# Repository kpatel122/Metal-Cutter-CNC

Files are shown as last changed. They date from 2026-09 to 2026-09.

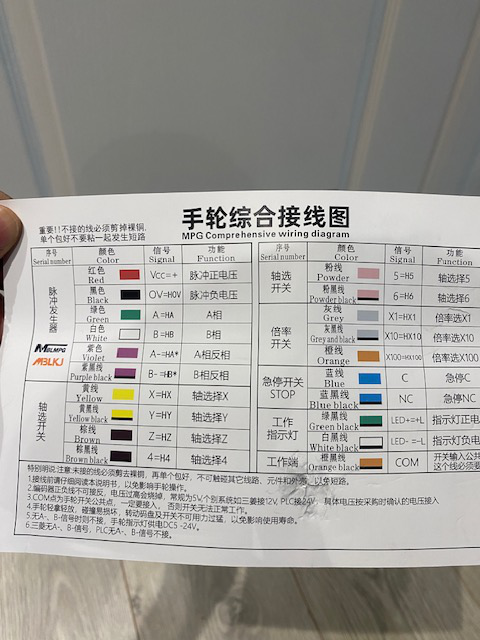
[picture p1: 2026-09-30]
MPEG Handwheel/encoder1.JPG

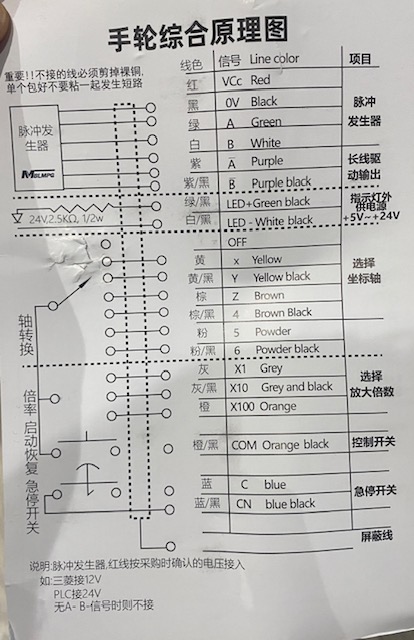
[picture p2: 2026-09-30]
MPEG Handwheel/encoder2.jpg

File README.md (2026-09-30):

# Metal Cutter CNC Machine
PrintNC Implementation based on the Metal Cutter variation.
https://wiki.printnc.info/en/home

(https://youtu.be/oM1bcv8IxZg)

Shield: [][cc-by-nc-sa]

This work is licensed under a
[Creative Commons Attribution-NonCommercial-ShareAlike 4.0 International License][cc-by-nc-sa].

[][cc-by-nc-sa]

[cc-by-nc-sa]: http://creativecommons.org/licenses/by-nc-sa/4.0/
[cc-by-nc-sa-image]: https://licensebuttons.net/l/by-nc-sa/4.0/88x31.png
[cc-by-nc-sa-shield]: https://img.shields.io/badge/License-CC%20BY--NC--SA%204.0-lightgrey.svg

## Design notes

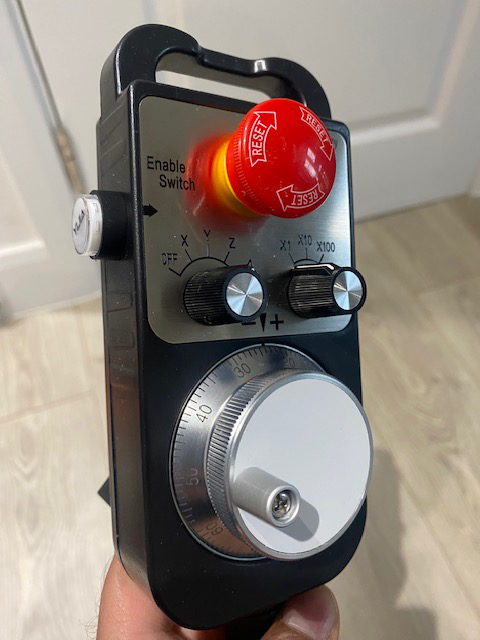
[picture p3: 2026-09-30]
MPEG Handwheel/encoder_pic.JPG

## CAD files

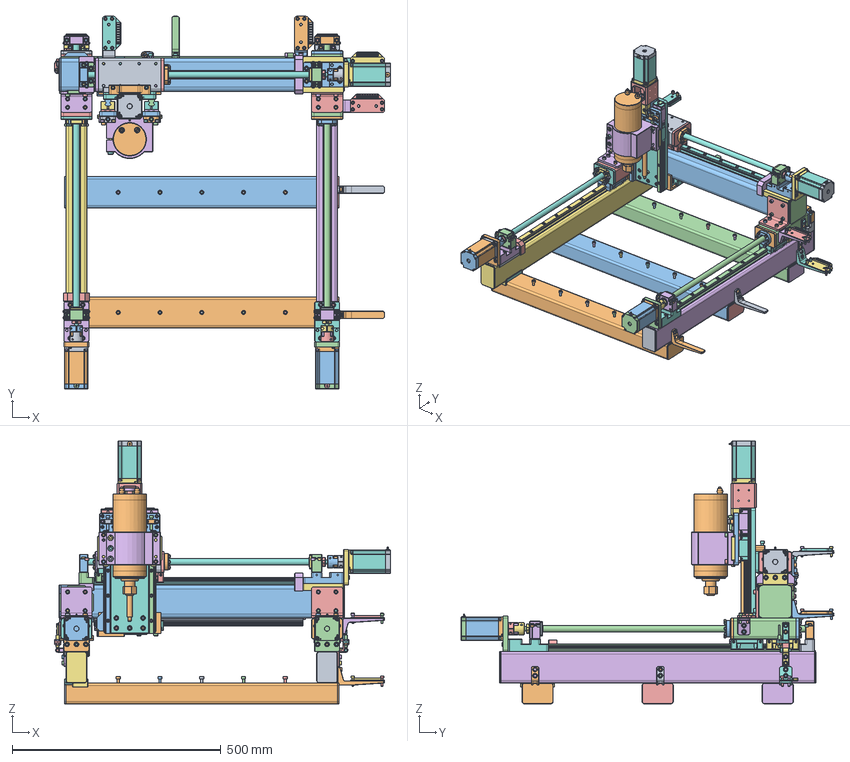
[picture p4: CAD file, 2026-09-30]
CAD/metal-cutter.FCStd
804.3 x 891.8 x 629.0 mm
Wasteboard M6x20
Wasteboard M6x001
Wasteboard M6x002
Wasteboard M6x003
Wasteboard M6x004
Wasteboard M6x005
Wasteboard M6x006
Wasteboard M6x007
Wasteboard M6x008
Wasteboard M6x009
Wasteboard M6x010
Wasteboard M6x011
Wasteboard M6x012
Wasteboard M6x013
Wasteboard M6x014
M6x12
M6x001
M6x002
M6x003
M6x004
M6x005
M6x006
M6x007
M6x008
M6x009
M6x010
M6x011
M6x012
M6x013
M6x014
M5x20
M5x001
M5x002
M5x003
M5x004
M5x005
M5x006
M5x007
M5x008
M5x009
M6x30
M6x016
M6x017
M6x018
M6x019
M6x020
M6x021
M6x50
M6x023
M6x024
M6x025
M6x026
M6x027
M4x16
M4x001
M4x002
M4x003
M6x50 (4)
M6x50 (4)001
M6x50 (4)002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

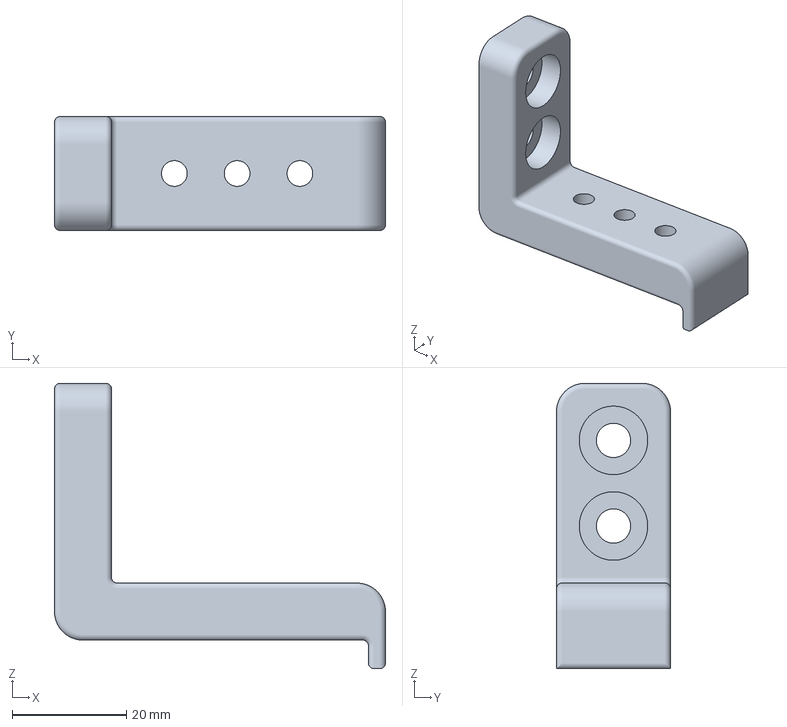
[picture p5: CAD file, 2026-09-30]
Fabrication/3D Printed Milled Parts/Common/chain-mount-holder-2-variation.3mf
58.0 x 20.0 x 50.0 mm

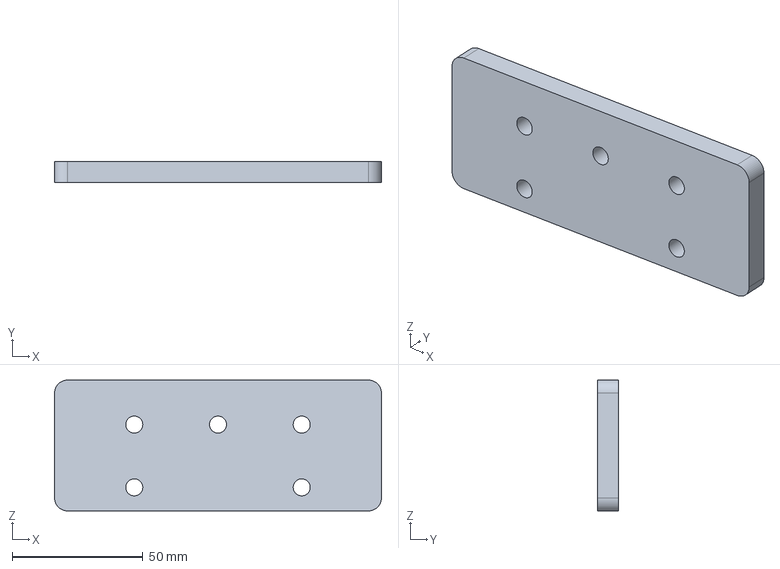
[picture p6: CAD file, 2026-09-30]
Fabrication/3D Printed Milled Parts/X Axis/XAxis-Shim.FCStd
125.0 x 8.00 x 50.0 mm

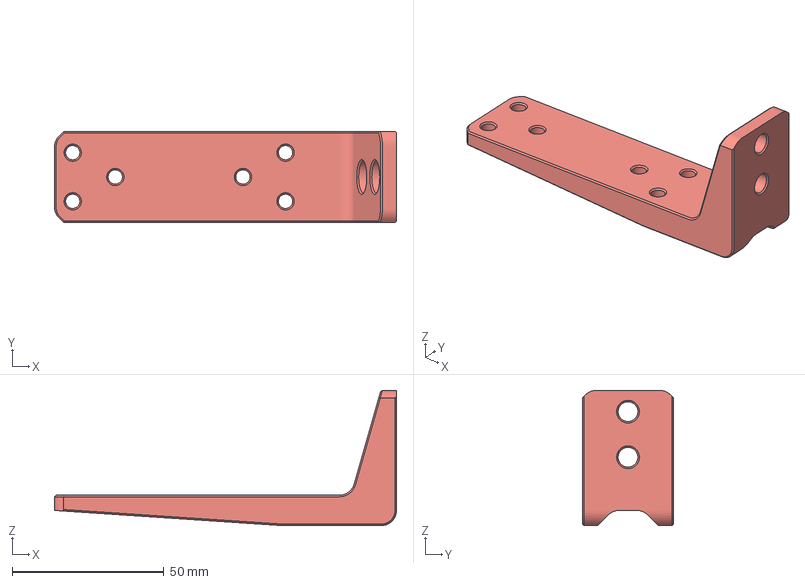
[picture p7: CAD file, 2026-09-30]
Fabrication/3D Printed Milled Parts/Y Axis/Cable-Chain/YChain-Fixed.3mf
112.5 x 30.0 x 44.5 mm

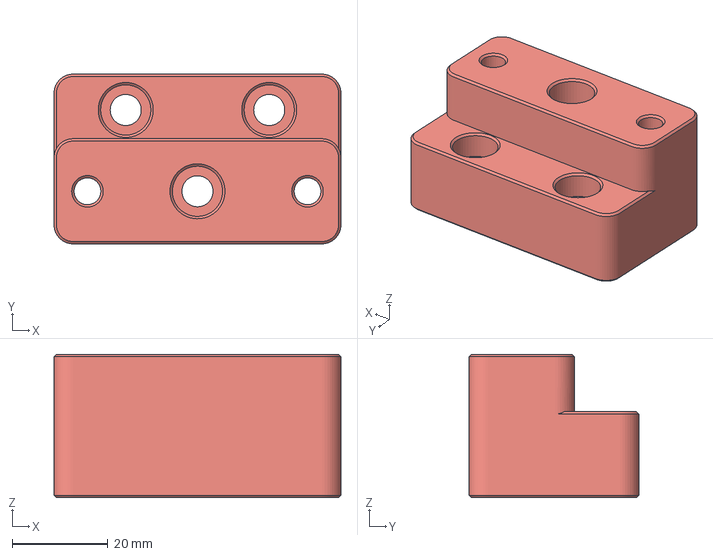
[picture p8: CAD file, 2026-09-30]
Fabrication/3D Printed Milled Parts/Y Axis/Y BF12 Riser.3mf
60.0 x 35.5 x 30.0 mm

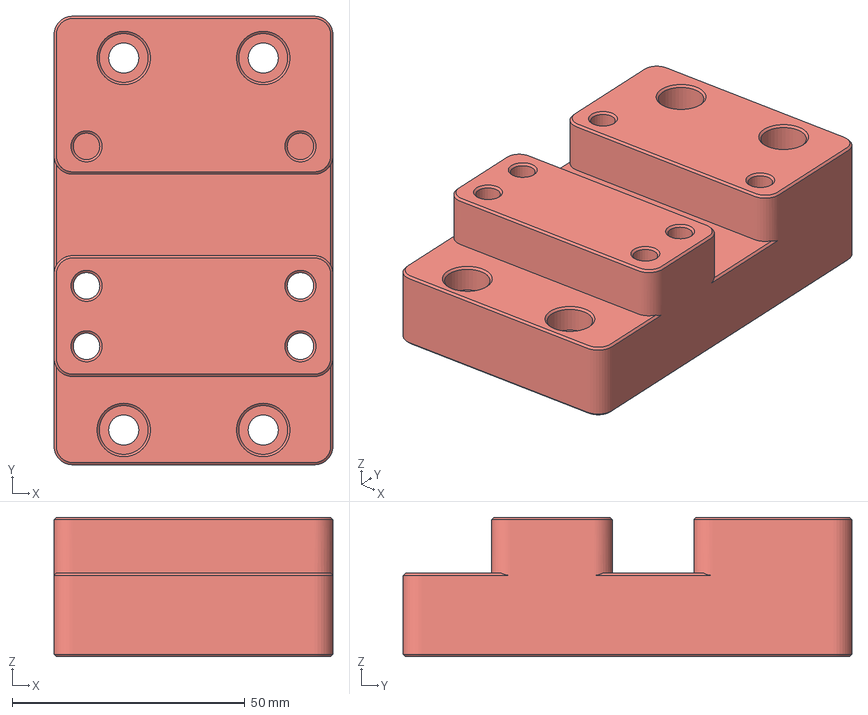
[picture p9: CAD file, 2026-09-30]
Fabrication/3D Printed Milled Parts/Y BKHM12 Riser.3mf
60.0 x 96.5 x 30.0 mm

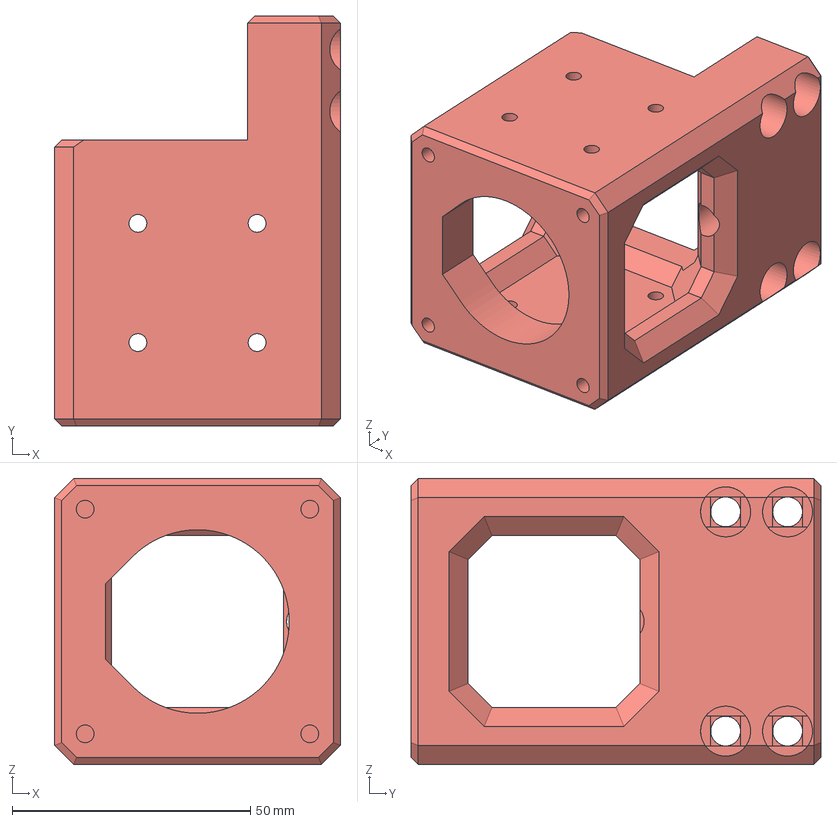
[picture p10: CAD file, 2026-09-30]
Fabrication/3D Printed Milled Parts/Z Axis/Z Nema23 Stepper Mount.3mf
60.0 x 86.0 x 60.0 mm

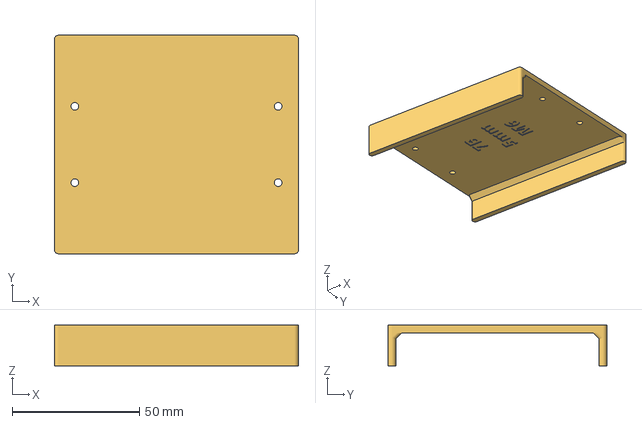
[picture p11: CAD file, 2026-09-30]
Fabrication/Printed Drill Guides/7B XGantry-BKHM Drill Guide.3mf
96.0 x 86.0 x 16.0 mm

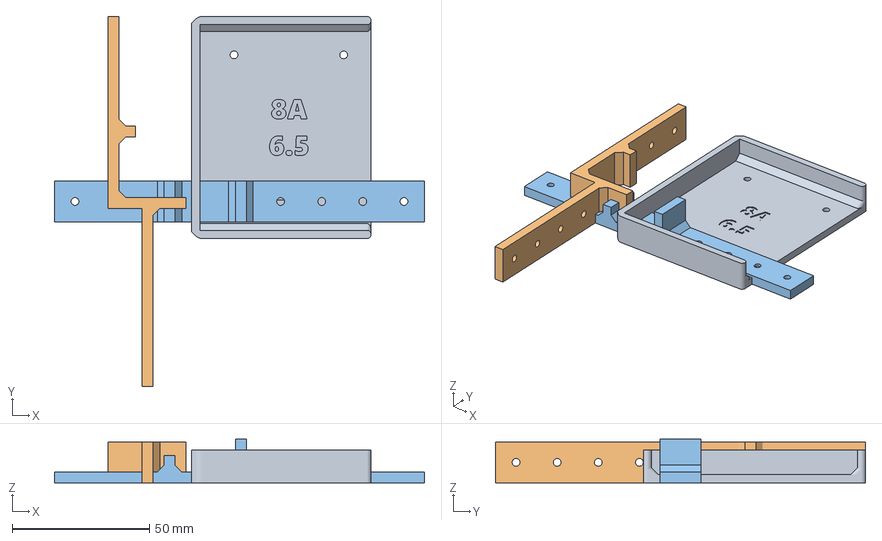
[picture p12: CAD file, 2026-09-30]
Fabrication/Printed Drill Guides/X Axis/8A X Top Roller-Carriage Drill Guide.3mf
135.0 x 135.0 x 16.0 mm
10A Yaxis Chain and Sensor Drill Guide
10B Xaxis Chain and Sensor Drill Guide

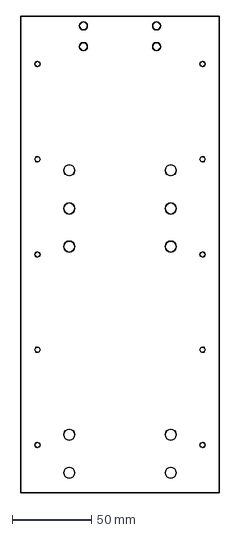
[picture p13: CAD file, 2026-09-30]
Fabrication/Z Axis/Wood Temp ZAxis/ZPlateTop.dxf
125.0 x 300.0 mm

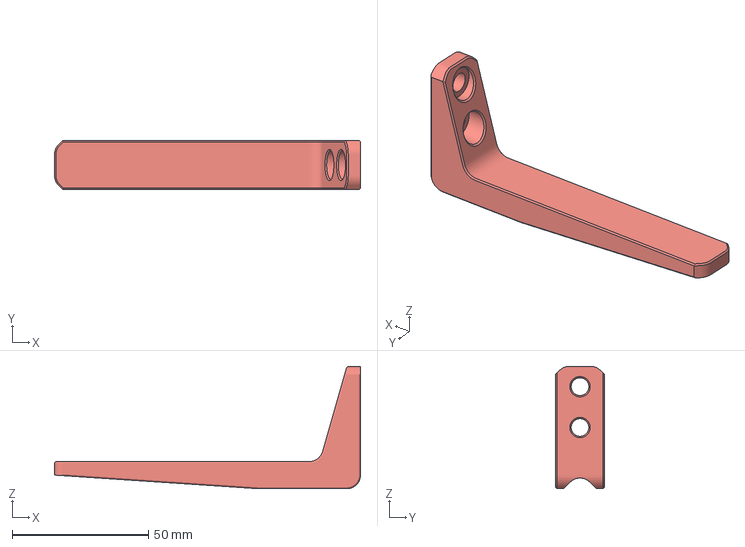
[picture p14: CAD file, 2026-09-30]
Fabrication/3D Printed Milled Parts/Y Axis/Cable-Chain/YChain-std.3mf
112.5 x 18.0 x 45.0 mm

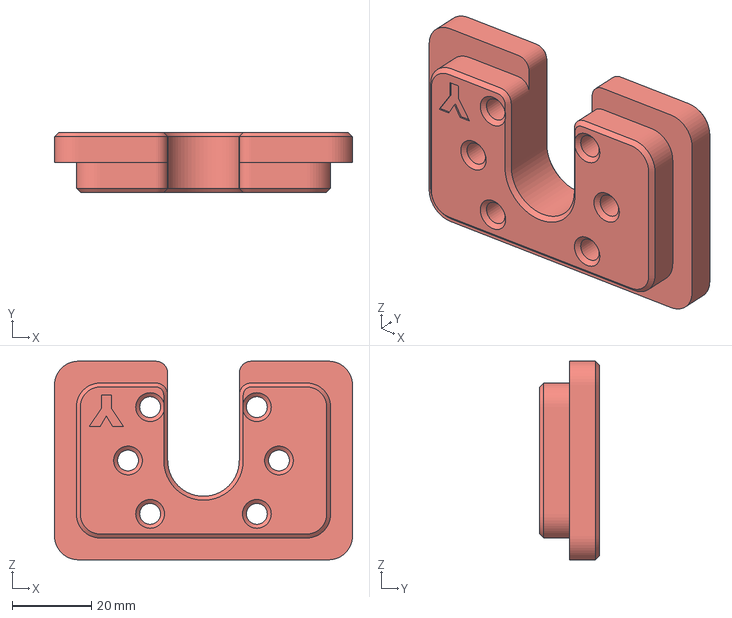
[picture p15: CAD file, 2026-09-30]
Fabrication/3D Printed Milled Parts/Y Axis/Y2 1610 Fill Plate.3mf
75.0 x 15.0 x 50.0 mm

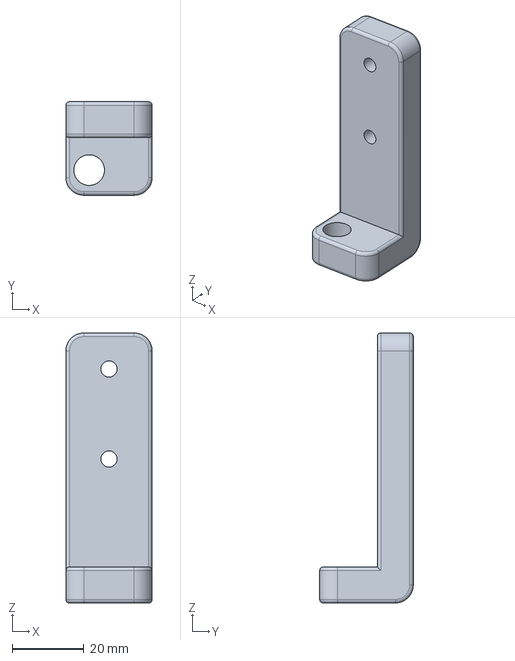
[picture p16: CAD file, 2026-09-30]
Fabrication/3D Printed Milled Parts/Z Axis/limit-switch-holder-z-axis.FCStd
24.0 x 26.0 x 75.0 mm

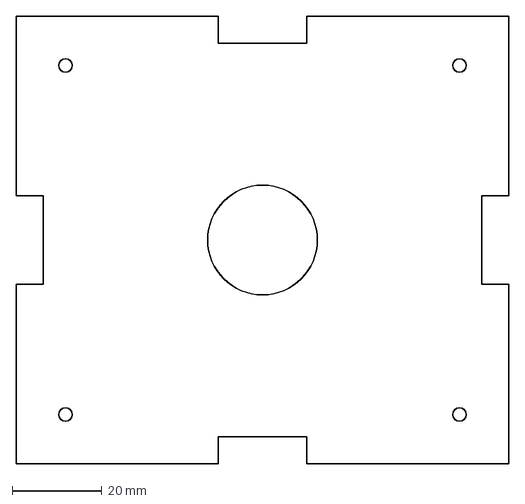
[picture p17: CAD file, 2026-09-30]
Fabrication/Front Panel/switch-panel-Sidesright.dxf
110.0 x 100.0 mm

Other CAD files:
Fabrication/Front Panel/switch-panel-front.dxf
Fabrication/3D Printed Milled Parts/Common/chain-mount-holder-2.3mf
Fabrication/3D Printed Milled Parts/X Axis/X BKHM12 Riser.3mf
Fabrication/3D Printed Milled Parts/Common/chain-mount-Body.3mf
Fabrication/3D Printed Milled Parts/Common/chain-mount-holder-1-variation.3mf
Fabrication/3D Printed Milled Parts/Common/chain-mount.FCStd
Fabrication/3D Printed Milled Parts/X Axis/7A XGantry-BF Drill Guide.3mf
Fabrication/3D Printed Milled Parts/X Axis/X 1610 Nut Plate.3mf
Fabrication/3D Printed Milled Parts/X Axis/X BF12 Riser.3mf
Fabrication/3D Printed Milled Parts/X Axis/X Nema23 Plate.3mf
Fabrication/3D Printed Milled Parts/X Axis/X-axis-homing-switch-mount.FCStd
Fabrication/3D Printed Milled Parts/X Axis/XAxis-Shim-Body.3mf
Fabrication/3D Printed Milled Parts/X Axis/XAxisOffesetBracket-Body.3mf
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

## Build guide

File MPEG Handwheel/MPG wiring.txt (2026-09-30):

P1 Expansion port
DB25	Mesa	MPG-wire-colour	Function
15		IO37	Brown			Z Select	
16		IO39	Yellow/Black	Y Select
17		IO41	Yellow			X Select
10		IO47	Gray			X1
11		IO48	Gray/Black		X10
12		IO49	Orange			x100
18		GND		Orangle/Black	switches GND (v5 gnd)

TB2
Mesa	MPG-wire-colour	Function 
1		White/Black		LED-
6		Green/Black		LED+
12		Red				+5V
9		Black			gnd (5v gnd)
7		Green			A+
8		Purple			A-
10		White			B+
11		Purple/Black	B-

TB3
Mesa	MPG-wire-colour	Function 
IO10 	Blue/Black		E-STOP-INPUT
GND     Blue			E-STOP-GND (24v gnd) (ground of 24V Power not 5v Power)

ESTOP WIRING (NC to GND)

MPEG and front panel estop wiring
IO10(mesa) -> Blue black wire mpeg (NC)->MPEG WHEEL ESTOP-> BLUE wire mpeg (COM)-> ETH breakout pin 6 -> PANEL ESTOP NC -> GND (ETH breakout GND)
Mesa IO10 → blue/black → [MPG NC] → blue → ETH pin 6 → [Panel NC] → GND

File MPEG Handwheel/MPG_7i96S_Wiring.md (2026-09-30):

# Wiring Guide: Mesa 7i96S to 18-Wire MPG Pendant

**Project:** PrintNC CNC Build  
**Date:** March 1, 2026  
**Hardware:** Mesa 7i96S Ethernet Card + 18-Wire Chinese MPG Pendant

---

### **Mesa Jumper Configuration**
To support the differential signals (A/A- and B/B-) from the pendant:
*   Set Jumpers **W1, W2, and W3** to the **RIGHT-HAND** position (Differential Mode).

---

## 2. Isolated Inputs: Axis & Multiplier (TB3)
The switches and buttons are wired to the isolated input block. This guide assumes a standard **24V Sourcing (PNP)** setup.

### **Input Mapping**
# Mesa MPG Wiring Reference

### P1 Expansion Port
| DB25 | Mesa | MPG-wire-colour | Function |
| :--- | :--- | :--- | :--- |
| 15 | IO37 | Brown | Z Select |
| 16 | IO39 | Yellow/Black | Y Select |
| 17 | IO41 | Yellow | X Select |
| 10 | IO47 | Gray | X1 |
| 11 | IO48 | Gray/Black | X10 |
| 12 | IO49 | Orange | x100 |
| 18 | GND | Orangle/Black | switches GND (v5 gnd) |

### TB2
| Mesa | MPG-wire-colour | Function |
| :--- | :--- | :--- |
| 1 | White/Black | LED- |
| 6 | Green/Black | LED+ |
| 12 | Red | +5V |
| 9 | Black | gnd (5v gnd) |
| 7 | Green | A+ |
| 8 | Purple | A- |
| 10 | White | B+ |
| 11 | Purple/Black | B- |

### TB3
| Mesa | MPG-wire-colour | Function |
| :--- | :--- | :--- |
| IO10 | Blue/Black | E-STOP-INPUT |
| 24v-GND | Blue | E-STOP-GND |

---

## 4. Auxiliary: LED & Enable Switch
*   **Indicator LED:** 
    *   **Green/Black (LED+):** Connect to +5V or +24V.
    *   **White/Black (LED-):** Connect to Ground.
*   **Enable/Deadman Switch:** This is the button on the side of the pendant. 
    *   **Identification:** Use a multimeter to check for continuity between **Orange/Black (COM)** and the **Brown/Black** wire while the side button is pressed.
    *   **Mesa Pin:** Connect the identified wire to **TB3 Pin 8 (Input 7)**.

---

## 5. Chinese Label Translation Table
| Chinese Label | English Translation |
| :--- | :--- |
| **轴选** (Zhóu xuǎn) | Axis Selection |
| **倍率** (Bèilǜ) | Multiplier (X1, X10, X100) |
| **急停** (Jí tíng) | Emergency Stop |
| **指示灯** (Zhǐshì dēng) | Indicator LED |
| **脉冲发生器** (Màichōng fāshēng qì) | Pulse Generator (MPG Wheel) |
| **COM** | Switch Common (Return Path) |

---

### **Pre-Power Validation**
Before turning on the machine:
1.  Check that the Red/Black power wires are not swapped.
2.  Verify that turning the Axis knob sends +24V to the expected Mesa Input pin.
3.  Ensure the E-Stop shows as "Closed" (high signal) when not pressed and "Open" (low signal) when pressed.

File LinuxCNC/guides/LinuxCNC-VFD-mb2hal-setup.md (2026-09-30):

# Optidrive E3 — mb2hal Setup (LinuxCNC Host)

Goal: replace the manual `mbpoll` commands in `commands.txt` with a HAL component
(`mb2hal`) that runs continuously inside LinuxCNC, exposing VFD run/stop, speed,
and status as HAL pins. These pins then get netted to the existing spindle
signals in `printnc-test1.hal` (`spindle.0.on`, `spindle.0.speed-out-abs`, etc.)
so the Axis GUI's existing spindle controls drive the VFD over Modbus.

Do all of this on the LinuxCNC controller machine, not the dev machine.

Syntax below is pulled directly from the LinuxCNC 2.9 docs
(`linuxcnc.org/docs/2.9/html/drivers/mb2hal.html`), matching your 2.9.8 install.

---

## 0. Before you start

- Confirm the RS485 connection works exactly as tested with `mbpoll` in
  `modbus-testing-guide.md` (same port, same 115200/8N1, slave ID 1).
- Have that file open — the register map (1 = control word, 2 = speed, 6 =
  status) and RPM-to-register scaling (register = RPM ÷ 6) come from there.
- **DI1 (hardware enable) is wired separately to Mesa OUT5 and is NOT part of
  this Modbus setup.** Don't remove or bypass that wiring — it's the fail-safe
  e-stop path and must keep working independently of whatever mb2hal is doing.

---

## 1. mb2hal.ini syntax reference

Two section types:

- `[MB2HAL_INIT]` — one global block
- `[TRANSACTION_00]`, `[TRANSACTION_01]`, ... — one per Modbus register you
  want to read or write

**`[MB2HAL_INIT]` keys:**

| Key | Required | Notes |
|---|---|---|
| `TOTAL_TRANSACTIONS` | Yes | Count of `[TRANSACTION_NN]` blocks below |
| `SLOWDOWN` | No | Seconds delay between transactions in the scan loop; `0.0` = as fast as possible |
| `HAL_MODULE_NAME` | No | Defaults to `mb2hal` — this is the prefix in all pin names |
| `INIT_DEBUG` | No | 0–4, startup log verbosity |

**`[TRANSACTION_NN]` keys:**

| Key | Required | Notes |
|---|---|---|
| `LINK_TYPE` | Yes | `serial` for our RS485 link |
| `SERIAL_PORT` | Only on first serial transaction | e.g. `/dev/ttyUSB0` |
| `SERIAL_BAUD` | Only on first serial transaction | `115200` |
| `SERIAL_BITS` | Yes | `8` |
| `SERIAL_PARITY` | Yes | `none` |
| `SERIAL_STOP` | Yes | `1` |
| `MB_SLAVE_ID` | Yes | `1` |
| `FIRST_ELEMENT` | Yes | Starting register **address** — see addressing warning below |
| `NELEMENTS` | Yes (unless using `PIN_NAMES`) | `1` for a single register |
| `MB_TX_CODE` | Yes | function code string, see table below |
| `HAL_TX_NAME` | No | custom name used in the resulting pin, max 28 chars |
| `MAX_UPDATE_RATE` | No | Hz cap on how often this transaction runs; `0.0` = unlimited |

**Function codes we need:**

| Purpose | `MB_TX_CODE` |
|---|---|
| Write control word / speed (FC6) | `fnct_06_write_single_register` |
| Read status word (FC3) | `fnct_03_read_holding_registers` |

**Resulting HAL pin names:** `mb2hal.<HAL_TX_NAME or transaction number>.<element index>.<type>`,
type being `.int` or `.float` for register transactions. With `NELEMENTS = 1`
the element index is always `00`.

** Addressing offset — confirmed correct on this install:**
The manual warns some Modbus masters use zero-based addressing and register
numbers may need `-1`. Confirmed empirically: with `FIRST_ELEMENT = 5`,
`vfd_status.00.int` read `64` (`0x0040`) when DI1 was enabled and `0` when
disabled — exactly the "No fault, Drive Ready" value documented in
`modbus-testing-guide.md` for register 6, and exactly matching the manual's
"bit 6 Drive Ready requires DI1 present" behavior. So `FIRST_ELEMENT =
register_number - 1` is correct:

| Manual register # | `mbpoll -r` | `FIRST_ELEMENT` |
|---|---|---|
| 1 (control word) | 1 | 0 |
| 2 (speed) | 2 | 1 |
| 6 (status) | 6 | 5 — confirmed live |

libmodbus applies this same zero-based convention uniformly across function
codes, so the two write transactions (registers 1 and 2) inherit the same
confirmed offset.

---

## 2. Draft `mb2hal.ini`

Create this next to `printnc-test1.hal`, e.g.
`/home/kp/Documents/Do_Backup/Projects/chips-cnc/LinuxCNC/mb2hal.ini`:

```ini
[MB2HAL_INIT]
TOTAL_TRANSACTIONS = 3
SLOWDOWN = 0.0
HAL_MODULE_NAME = mb2hal

[TRANSACTION_00]
LINK_TYPE = serial
SERIAL_PORT = /dev/ttyUSB0
SERIAL_BAUD = 115200
SERIAL_BITS = 8
SERIAL_PARITY = none
SERIAL_STOP = 1
MB_SLAVE_ID = 1
FIRST_ELEMENT = 0
NELEMENTS = 1
MB_TX_CODE = fnct_06_write_single_register
HAL_TX_NAME = vfd_control_word
MAX_UPDATE_RATE = 5.0

[TRANSACTION_01]
LINK_TYPE = serial
MB_SLAVE_ID = 1
FIRST_ELEMENT = 1
NELEMENTS = 1
MB_TX_CODE = fnct_06_write_single_register
HAL_TX_NAME = vfd_speed
MAX_UPDATE_RATE = 5.0

[TRANSACTION_02]
LINK_TYPE = serial
MB_SLAVE_ID = 1
FIRST_ELEMENT = 5
NELEMENTS = 1
MB_TX_CODE = fnct_03_read_holding_registers
HAL_TX_NAME = vfd_status
MAX_UPDATE_RATE = 5.0
```

Note `SERIAL_PORT`/`SERIAL_BAUD` only appear once, on the first serial
transaction — the rest share that link.

`MAX_UPDATE_RATE = 5.0` (every ~200ms) keeps all three transactions well
under the VFD's 3-second Modbus watchdog (SC-F01 trip), same reasoning as the
manual `mbpoll` watchdog loop you were running before. Because mb2hal re-writes
the control word and speed registers every cycle (not just on change), those
two writes are *also* independently satisfying the watchdog, on top of the
status read.

---

## 3. Test mb2hal standalone — do NOT touch `printnc-test1.hal` yet

Same principle as validating with `mbpoll` before wiring anything: prove the
component works in isolation before touching the real config.

```bash
halrun -I
loadusr -W mb2hal config=/path/to/mb2hal.ini
halcmd show pin mb2hal
```

You should see (confirmed against a real load — write transactions and read
transactions name their pins differently):
```
mb2hal.vfd_control_word.00        (float IN  — fnct_06 write, no type suffix)
mb2hal.vfd_speed.00               (float IN  — fnct_06 write, no type suffix)
mb2hal.vfd_status.00.float        (fnct_03 read — both .float and .int exist)
mb2hal.vfd_status.00.int
mb2hal.<name>.num_errors          (u32 OUT, per transaction — watch this, see below)
```

**Do not run a competing `mbpoll` on the same port at the same time.** A
single RS485 adapter can't be shared by two Modbus masters talking
simultaneously — if you leave a manual `mbpoll` watchdog running in another
terminal while `mb2hal` is also polling, every transaction on both sides will
fail. Check nothing else has the port open before loading mb2hal:
```bash
fuser -v /dev/ttyUSB0
```
Kill anything shown there first. If `num_errors` on any pin is climbing every
cycle with the VFD powered on, this — or a wrong `SERIAL_PORT`/wiring fault —
is the thing to rule out. (On this install, `num_errors` stayed at 0 and
`vfd_status.00.int` correctly read `0`/`64` with DI1 disabled/enabled,
confirming both comms and the register addressing offset are good.)

**Confirm the write side: set RPM / start / stop.** With DI1/OUT5 enabled,
run this full sequence with halcmd:

```bash
# 1. Set speed (~1000 RPM)
halcmd setp mb2hal.vfd_speed.00 167

# 2. Start
halcmd setp mb2hal.vfd_control_word.00 1
halcmd getp mb2hal.vfd_status.00.int
# expect 65 (64 Ready + 1 Running) instead of 64. Watch the spindle
# physically spin up too. Confirmed live on this install: 0 (disabled) ->
# 64 (enabled, stopped) -> 65 (enabled, running) -> 64 (stopped again).

# 3. Stop
halcmd setp mb2hal.vfd_control_word.00 0
halcmd getp mb2hal.vfd_status.00.int
# expect bit 0 clears — back to 64 (Ready, not Running). Watch the spindle
# ramp down per P-04 deceleration time.

exit
```

Don't move to step 4 until set-RPM/start/stop all behave exactly as they did
under manual `mbpoll` control.

---

## 4. Wire it into `custom.hal` (not `printnc-test1.hal`)

Your `printnc-test1.ini` already loads `custom.hal` after the PNCconf-generated
file:

```ini
[HAL]
HALFILE = printnc-test1.hal
HALFILE = custom.hal
```

Put all mb2hal + Modbus wiring in `custom.hal` so a future PNCconf regeneration
doesn't wipe it out. Add (pin names confirmed against a real `mb2hal` load in
step 3 — write pins have no `.int`/`.float` suffix, only reads do):

```hal
# --- VFD Modbus bridge (mb2hal) ---
loadusr -W mb2hal config=/path/to/mb2hal.ini

# RPM -> Optidrive register scaling (register = RPM / 6, per modbus-testing-guide.md)
loadrt scale names=spindle-rpm-to-reg
addf spindle-rpm-to-reg servo-thread
setp spindle-rpm-to-reg.gain 0.16667

net spindle-vel-cmd-rpm-abs => spindle-rpm-to-reg.in
net spindle-reg-speed       <= spindle-rpm-to-reg.out
net spindle-reg-speed       => mb2hal.vfd_speed.00

# spindle.0.on is a bit signal; mb2hal's write pin is float — HAL does NOT
# auto-convert between types on a net, so bridge it through conv_bit_float
loadrt conv_bit_float count=1
addf conv-bit-float.0 servo-thread

net spindle-enable          => conv-bit-float.0.in
net spindle-enable-float    <= conv-bit-float.0.out
net spindle-enable-float    => mb2hal.vfd_control_word.00

# --- VFD hardware enable (DI1) — independent of Modbus, fails safe on e-stop ---
net machine-is-enabled      => hm2_7i96s.0.outm.00.out-05
```

`spindle-vel-cmd-rpm-abs`, `spindle-enable`, and `machine-is-enabled` already
exist as signals in `printnc-test1.hal` — you're adding new destinations for
them, not redefining them. `machine-is-enabled` and `hm2_7i96s.0.outm.00.out-05`
are both bit type already, so that net doesn't need conversion — only
`spindle-enable` → mb2hal's float pin does.

`conv-bit-float.0.out` gives 0.0/1.0, matching control word values you
already validated by hand (bit 0 = run enable). Fault-reset (control word
value 4, bit 2) isn't wired here; add a separate momentary HAL bit + pyvcp
button later if you want that exposed too. Direction (FWD/REV) isn't in the
Optidrive's control word at all per the manual's register map — this spindle
only supports single-direction run via Modbus.

---

## 5. Full end-to-end test

1. Start LinuxCNC normally with this config.
2. `halcmd show pin mb2hal` — confirm it loaded and `vfd_status` is updating
   continuously (this is your watchdog — if it stops polling for >3s the
   drive will trip SC-F01).
3. In Axis, home all axes first — MDI (including M3/M5) won't execute on
   this config until the machine is homed. Then use MDI:
   ```
   M3 S1000
   ```
   Confirm the VFD ramps up to ~1000 RPM.
   ```
   M5
   ```
   Confirm it ramps down and stops.

   While a command is active, open a **separate terminal** (don't use
   `halrun` — LinuxCNC already owns the running HAL instance, so plain
   `halcmd` connects straight to it) and check the signals are actually
   propagating, not just coincidentally working:
   ```bash
   halcmd show pin mb2hal              # num_errors flat, vfd_status = 65 while running, 64 when stopped
   halcmd show pin spindle-rpm-to-reg   # .in = commanded RPM, .out = RPM / 6
   halcmd show sig spindle-enable       # toggles 1/0 with M3/M5
   ```
4. Try the Axis manual spindle controls (forward/stop buttons) directly.
5. Trigger e-stop and confirm the VFD drops out (DI1 / OUT5 path) regardless
   of what mb2hal's control word pin says — this is the fail-safe check, don't
   skip it.
6. Leave it running for several minutes at a stop/idle state and confirm no
   SC-F01 trips occur (proves the continuous poll is satisfying the watchdog
   even when not actively commanding speed changes).

---

## 6. Rollback

If anything misbehaves, comment out the mb2hal/scale/net block added in step 4
from `custom.hal` — `printnc-test1.hal` is untouched, so the machine's axes,
homing, jogging, and e-stop remain fully functional without spindle control.

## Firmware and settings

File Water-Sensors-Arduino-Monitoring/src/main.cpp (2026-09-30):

#include <Arduino.h>
#include "display.h"
#include "serial_comms.h"
#include "temp_sensor.h"
#include "flow_sensor.h"

void setup(void)
{
    serial_comms_init();
    display_init();
    temp_sensor_init();
    flow_sensor_init();
}

void loop(void)
{
    const char *msg = serial_comms_poll();
    if (msg != NULL)
    {
        display_show_message(msg);
        serial_comms_clear_terminal();
    }

    if (temp_sensor_update())
    {
        display_show_temp(temp_sensor_get_celsius());
    }

    if (flow_sensor_update())
    {
        display_show_flow(flow_sensor_get_lpm(), flow_sensor_is_flowing());
    }
}

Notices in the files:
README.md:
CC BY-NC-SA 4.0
